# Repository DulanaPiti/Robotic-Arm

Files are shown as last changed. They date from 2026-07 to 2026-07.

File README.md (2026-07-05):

# 6-DOF Industrial Robotic Arm

## Overview
This repository contains the hardware design, simulation files, and documentation for a 6-DOF (Degrees of Freedom) industrial robotic arm. This system was developed by team **Neural Nexus** for the EN2160 Electronic Design Realization module. 

The project encompasses custom high-speed PCB designs, mechanical part models, and a complete simulation environment for testing kinematics and control logic.

## Repository Structure

* **`/Encoder PCB files`**
  * Contains the Altium Designer schematics, PCB layouts, and manufacturing files (Gerbers/NC Drill) for the joint encoder boards.
* **`/Main PCB files`**
  * Contains the Altium Designer project for the main control board, including power distribution and signal routing.
* **`/Part files`**
  * Mechanical CAD models (e.g., STEP/STL files) for the robotic arm links, base, and actuator mounts.
* **`/Robotic ARM Simulation`**
  * Simulation environment files to test and visualize the 6-DOF movements and control algorithms.

## Tools & Technologies Used
* **Hardware Design:** Altium Designer (Multi-layer PCB routing)
* **Simulation:** Made using Python
* **Mechanical CAD:** SolidWorks

## Getting Started
### Prerequisites
To view or modify the files in this repository, you will need:
* Altium Designer (for `.PcbDoc` and `.SchDoc` files)

## Team
**Neural Nexus**
* Dulana Nadith Pitiwaduge
* Lasan Perera
* Deneth Priyadarshana
* Isitha Dinujaya
* Mokshan Colombage

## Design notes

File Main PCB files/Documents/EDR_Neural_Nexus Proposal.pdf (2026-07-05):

# Project Proposal: Modular 6-DOF Industrial Robotic Arm

### NEURAL NEXUS

- One arm. Unlimited applications -

### 1. Executive Summary

This proposal outlines the strategic development and rapid market entry of an affordable, industrial-grade 6-Degrees of Freedom (DOF) robotic arm by NEURAL NEXUS. Industrial automation in Sri Lanka is currently stifled by the prohibitive cost of imported systems (1.0–1.5 million LKR). Our mission is to democratize high-end robotics by providing a performance-equivalent, modular system priced under 0.8 million LKR. This system is specifically tailored for the unique constraints of local SMEs, garment factories, and educational institutions, facilitating a rapid transition towards “Industry 4.0” through localized innovation and a compressed 3-month development cycle.

### 2. Market Justification & Target Segments

By 2026, the global shift toward “Physical AI” has transformed automation from a luxury into a competitive necessity. While developed nations have already reached a peak of efficiency through the implementation of “dark factories”—fully autonomous, unlit production lines emerging markets like Sri Lanka face a significant innovation-execution gap.
Despite a surplus of innovative ideas, the lack of local resources and high import costs typically delay the domestic adoption of such technologies by an estimated 6 to 8 years. Our development of a localized robotic arm serves as a strategic intervention to bridge this gap through three primary objectives:
- Lead-Time Reduction: By providing immediate, locally-available automation, we significantly reduce the lead time for industries that are currently underserved by global manufacturers focused on highvolume automotive lines.
- Market Alignment: We are entering a market where the industry explicitly expects local automation solutions. By offering a high-precision, low-cost alternative, we make advanced robotics accessible to a broader range of local enterprises.
- Ecosystem Development: Beyond the hardware, this project acts as a catalyst for a domestic supply chain. Our approach encourages the production of custom motors and specialized industrial materials within Sri Lanka, fostering a self-sustaining ecosystem for local high-tech manufacturing.

Primary Target Segments
- SME Manufacturing: Packaging, food processing, bottling, and repetitive material handling.
- Garment Industry: Automating fabric sorting, folding, and repetitive assembly tasks.
- Electronics Assembly: High-speed PCB placement, soldering, and quality inspection.
- Educational Institutes: Providing universities with a robust R&D platform for AI training.STEM Education
- Custom Automation: Local startups requiring non-standard tool integrations for niche processes.

### 3. Technical Specifications

To ensure industrial-grade reliability, our system adheres to the following engineering benchmarks:

Component/Feature | Specification / Requirement
Degrees of Freedom (DOF) | 6 (Waist, Shoulder, Elbow, and 3-Axis Spherical Wrist)
Rated Payload / Reach | 3.0 kg (Rated) / 750 mm (Spherical workspace)
Repeatability Spec | ±0.5 mm (High-resolution absolute encoders)
Structural Integrity | CNC-machined Aerospace-grade Aluminum and Steel
Control Architecture | Closed-loop real-time control; Inverse Kinematics (IK) processing
Drive System | High-torque stepper motors with customized plantery gearboxes
Safety Systems | Emergency Stop, Overcurrent Protection, Physical limit Sensors

Table 1: Core Technical Benchmarks for Industrial Deployment

### 4. Modular Ecosystem: Swappable Tool-Heads

The versatility of the NEURAL NEXUS arm lies in its rapid-change modular interface:
– Gripper Head: Mechanical picking and sorting for small parts.
– Vacuum Suction Head: Ideal for box handling, palletizing, and delicate flat sheets. – Screwdriver Head: Precision torque-controlled assembly for electronics.
– Vision Module: Integrated AI-enabled camera for real-time object recognition.

### 5. Market Approach & Sales Strategy

NEURAL NEXUS differentiates itself through a disruptive price-to-performance ratio and a localized support ecosystem designed to minimize industrial downtime.

Competitive Pricing Model
Our pricing is structured to lower the barrier to entry while maintaining sustainable margins.

– Target Selling Price (Base Unit): 350,000 – 500,000 LKR.

– Price Advantage: ∼50% lower than entry-level imported units from major global brands.

– Add-on Modules: Specialized heads priced at 35,000 – 85,000 LKR.

– Software Tiers: Core control is included; AI-vision upgrades are sold as yearly licenses.

Sales Channels & Market Penetration
To capture the Sri Lankan market effectively, we utilize a multi-pronged approach:

– The ”Trojan Horse” Strategy: Enter a factory by automating one specific bottleneck (e.g., bottling) to demonstrate ROI within 6 months, justifying further installations.

– Automation-as-a-Service (AaaS): Offer a lease model where clients pay per 1,000 cycles.

– B2B Partnerships: Partnering with local consultants who design production lines.

– Education Bundles: Providing technical colleges with a ”Robotics Lab Starter Kit.”

The Local Support Advantage
The primary deterrent for local firms is the lack of on-site support for international systems.

– 24/48-Hour Service Guarantee: On-site support and local inventory of spare parts.

– Customization Service: Bespoke tool-head design for localized industry needs (e.g., textile handling).

### 6. Project Budget (Estimated for MVP Prototype)

Item Category | Description | Cost (LKR)
Actuators & Feedback | 6x Industrial Grade High-torque steppers with Encoders | 150,000
Controller & Logic | Industrial-grade Central Controller and I/O interface | 45,000
Structural Components | CNC-machined metal frame, precision bearings, and housing | 50,000
Initial Tooling | Prototypes for Gripper and Vacuum Suction modules | 35,000
Sensors & Safety | Limit switches, Emergency stop, Power management circuits | 40,000
R&D & Iteration | Software development and rapid prototyping contingency | 60,000
TOTAL COST | | 380,000 LKR

Table 2: Prototype Development Budget (MVP Phase)

### 7. Accelerated Implementation Timeline (3 Months)

The project utilizes a parallel-track development strategy to meet a 12-week deployment goal.

– Month 1: Kinematic modeling, structural design validation, and component sourcing.
– Month 2: CNC fabrication of frames, actuator mounting, and control logic integration.
– Month 3: Stress testing, UI/UX refinement for friendly visible control, and pilot deployment.

### 8. Future Improvements

NEURAL NEXUS aims to integrate Agentic AI for autonomous task re-planning.A core improvement of this project is the development of a highly intuitive Graphical User Interface (GUI) designed to bridge the technical gap between complex robotics and the end-user. Traditionally, reconfiguring a robotic arm for a new task requires specialized knowledge of programming languages or proprietary industrial controllers. Our solution removes this barrier

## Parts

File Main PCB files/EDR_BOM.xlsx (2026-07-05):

Line # | Name | Description | Designator | Revision ID | Revision State | Revision Status | Quantity | TargetPrice | Manufacturer 1 | Manufacturer Part Number 1 | Manufacturer Lifecycle 1 | Supplier 1 | Supplier Part Number 1 | Supplier Unit Price 1 | Supplier Subtotal 1
 | 0R | Resistor, AS 0603 0R Jumper 100mW, AEC-Q, Anti-Sulur | Bourns CR0603AJ/-000EAS | R26, SB1, SB2 |  | Not managed |  | 3 | 0 | Bourns | CR0603AJ/-000EAS | Volume Production | Mouser | 652-CR0603AJ/-000EAS | 0.02 | 0.2
 | 0.1uF 0805 | 0.1 ÂµF Â±10% 50V Ceramic Capacitor X7R 0805 (2012 Metric) | C27, C30 |  | Not managed |  | 2 | 0 | Samsung Electro-Mechanics | CL21B104KBCNNNC | Volume Production | DigiKey | 1276-1003-1-ND | 0.1 | 0.2
 | 1k | 1 kOhms Â±1% 0.063W, 1/16W Chip Resistor 0402 (1005 Metric) Moisture Resistant Thick Film | R49 |  | Not managed |  | 1 | 0 | Yageo Group | RC0402FR-071KL | Volume Production | Mouser | 603-RC0402FR-071KL | 0.1 | 0.1
 | 1N4148W | Small Signal Diode, SOD-123F, 100V, 0.15A, 150Â°C | D1, D2 |  | Not managed |  | 2 | 0 | Diodes Inc. | 1N4148W-7-F | Volume Production | Avnet | 52R3924 | 0.117 | 0.234
 | 1N5819HW-7-F | Diode Schottky 40 V 1A Surface Mount SOD-123 | D12, D13 |  | Not managed |  | 2 | 0 | Diodes Inc. | 1N5819HW-7-F | Volume Production | Newark | 1N5819HW-7-F | 0.284 | 0.568
 | 1uF | 1 ÂµF Â±10% 6.3V Ceramic Capacitor X5R 0402 (1005 Metric) | C34 |  | Not managed |  | 1 | 0 | TAIYO YUDEN | JMK105BJ105KV-F | Not Recommended for New Design | Arrow Electronics | JMK105BJ105KV-F | 0.0015 | 0.0015
 | 1uF 0603 | 1 ÂµF -20%, +80% 16V Ceramic Capacitor Y5V (F) 0603 (1608 Metric) | C15, C17 |  | Not managed |  | 2 | 0 | Yageo Group | CC0603ZRY5V7BB105 | Volume Production | DigiKey | 311-1372-1-ND | 0.1 | 0.2
 | 1uF 0603 | 1 ÂµF -20%, +80% 16V Ceramic Capacitor Y5V (F) 0603 (1608 Metric) | C39 |  | Not managed |  | 1 | 0 | Yageo Group | CC0603ZRY5V7BB105 | Volume Production | DigiKey | 311-1372-1-ND | 0.1 | 0.1
 | 1.5 kOhm | 1.5 kOhms Â±1% 0.063W, 1/16W Chip Resistor 0402 (1005 Metric) Moisture Resistant Thick Film | R4 |  | Not managed |  | 1 | 0 | Yageo Group | RC0402FR-071K5L | Volume Production | Farnell | RC0402FR-071K5L | 0.00551 | 0.05507
 | 1.5 kOhm | 1.5 kOhms Â±1% 0.063W, 1/16W Chip Resistor 0402 (1005 Metric) Moisture Resistant Thick Film | R25, R34 |  | Not managed |  | 2 | 0 | Yageo Group | RC0402FR-071K5L | Volume Production | Farnell | RC0402FR-071K5L | 0.00551 | 0.05507
 | 2N7002LT3G | RoHS Compliant; Small package discrete | Q1, Q2 |  | Not managed |  | 2 | 0 | onsemi | 2N7002LT3G | Volume Production | Avnet | 09R9864 | 0.065 | 0.13
 | 2.2uF 0603 | 2.2 ÂµF Â±10% 25V Ceramic Capacitor X5R 0603 (1608 Metric) | C12, C13 |  | Not managed |  | 2 | 0 | Yageo Group | CC0603KRX5R8BB225 | Volume Production | Mouser | 603-CC603KRX5R8BB225 | 0.13 | 0.26
 | 3.3uH | FHD4020S-3R3MT | L2 |  | Not managed |  | 1 | 0 | Cjiang | FHD4020S-3R3MT | Unknown
 | 4.7uF 0603 | No Description Available | C23 |  | Not managed |  | 1 | 0 | Yageo Group | CC0603MRX5R8BB475 | Volume Production
 | 4.7uF X7R | C Series 0805 4.7 uF 10 V Â±10% Tolerance X7R SMT Multilayer Ceramic Capacitor | C24, C25 |  | Not managed |  | 2 | 0 | TDK | C2012X7R1A475K125AC | Volume Production | Arrow Electronics | C2012X7R1A475K125AC | 0.1822 | 0.3644
 | 4.7uF X7R | C Series 0805 4.7 uF 10 V Â±10% Tolerance X7R SMT Multilayer Ceramic Capacitor | C38 |  | Not managed |  | 1 | 0 | TDK | C2012X7R1A475K125AC | Volume Production | Arrow Electronics | C2012X7R1A475K125AC | 0.1822 | 0.1822
 | 5.1k | 5.1 kOhms Â±1% 0.063W, 1/16W Chip Resistor 0402 (1005 Metric) Automotive AEC-Q200 Thick Film | R47, R48, R52, R53 |  | Not managed |  | 4 | 0 | Stackpole Electronics | RMCF0402FT5K10 | Volume Production | Mouser | 708-RMCF0402FT5K10 | 0.012 | 0.12
 | 10k 0402 | 301010004 | J17, J19, R7, R8, R24 |  | Not managed |  | 5 | 0 | Yageo Group | RC0402JR-0710KL | Volume Production | Farnell | RC0402JR-0710KL | 0.006 | 0.05998
 | 10pF | 10 pF Â±5% 25V Ceramic Capacitor C0G, NP0 0402 (1005 Metric) | C4, C5 |  | Not managed |  | 2 | 0 | Yageo Group | CC0402JRNPO8BN100 | Volume Production | Newark | CC0402JRNPO8BN100 | 0.012 | 0.12
 | 10uF 0805 | SMD capacitor X7R(MURATA) with capacitance 10uF Tol.10%. Rated voltage 25Vdc 125C | C28, C29 |  | Not managed |  | 2 | 0 | Murata | GRM21BZ71E106KE15L | Volume Production | Conrad | 3425898 | 0.16272 | 0.32543
 | 12pF | 0402 12 pF 50 V Â±1% Tolerance C0G SMT Multilayer Ceramic Capacitor | C8, C9 |  | Not managed |  | 2 | 0 | Murata | GRM1555C1H120FA01D | Not Recommended for New Design | DigiKey | 490-6196-1-ND | 0.1 | 0.2
 | 20k | 20 kOhms Â±1% 0.1W, 1/10W Chip Resistor 0603 (1608 Metric) Moisture Resistant Thick Film | R31 |  | Not managed |  | 1 | 0 | Yageo Group | RC0603FR-0720KL | Volume Production | Farnell | RC0603FR-0720KL | 0.01 | 0.09996
 | 22R 0402 | 22 Ohms Â±1% 0.063W, 1/16W Chip Resistor 0402 (1005 Metric) Moisture Resistant Thick Film | R9, R10, R11, R12, R13, R14, R15, R16, R17, R18, R19, R20, R54, R55, R56, R57, R58 |  | Not managed |  | 17 | 0 | Yageo Group | RC0402FR-0722RL | Volume Production | Newark | RC0402FR-0722RL | 0.004 | 0.068
 | 22R 0402 | 22 Ohms Â±1% 0.063W, 1/16W Chip Resistor 0402 (1005 Metric) Moisture Resistant Thick Film | R38, R39, R40, R41, R42, R43 |  | Not managed |  | 6 | 0 | Yageo Group | RC0402FR-0722RL | Volume Production | Newark | RC0402FR-0722RL | 0.004 | 0.04
 | 22uF 1210 | SMD capacitor X7R(EIA) with capacitance 22uF Tol.10%. Rated voltage 25Vdc 125C | C31, C32 |  | Not managed |  | 2 | 0 | Murata | GRM32ER71E226KE15L | Volume Production | Conrad | 3424926 | 0.62762 | 1.26
 | 22.1k | 22.1 kOhms Â±1% 0.1W, 1/10W Chip Resistor 0603 (1608 Metric) Automotive AEC-Q200 Thick Film | R50 |  | Not managed |  | 1 | 0 | Stackpole Electronics | RMCF0603FT22K1 | Volume Production | DigiKey | RMCF0603FT22K1CT-ND | 0.1 | 0.1
 | 25MHZ | 25 MHz Â±30ppm Crystal 10pF 60 Ohms 4-SMD, No Lead | X2 |  | Not managed |  | 1 | 0 | Abracon | ABM8G-25.000MHZ-B4Y-T | Volume Production | Farnell | ABM8G-25.000MHZ-B4Y-T | 0.65974 | 0.65974
 | 32.768KHZ | Description | X1 |  | Not managed |  | 1 | 0 | Abracon | ABS07-32.768KHZ-7-T | Volume Production | Newark | ABS07-32.768KHZ-7-T | 0.578 | 0.578
 | 36.1k | RES SMD 36.1KOHM 0.1% 1/10W 0603 | R32 |  | Not managed |  | 1 | 0 | Yageo Group | RT0603BRD0736K1L | Volume Production | Mouser | 603-RT0603BRD0736K1L | 0.1 | 0.1
 | 47 kOhm | 47 kOhms Â±1% 0.1W, 1/10W Chip Resistor 0603 (1608 Metric) Moisture Resistant Thick Film | R35, R36, R37, R44, R45 |  | Not managed |  | 5 | 0 | Yageo Group | RC0603FR-0747KL | Volume Production | Mouser | 603-RC0603FR-0747KL | 0.013 | 0.13
 | 47.5k | 47.5 kOhms Â±1% 0.063W, 1/16W Chip Resistor 0402 (1005 Metric) Moisture Resistant Thick Film | R51 |  | Not managed |  | 1 | 0 | Yageo Group | RC0402FR-0747K5L | Volume Production | Arrow Electronics | RC0402FR-0747K5L | 0.0005 | 0.0005
 | 49.9 R | Resistor,Thick Film,49.9 Ohms,0.063 W,1%,SMT,0402,TCR 37 ppm/DegC,Cut Tape | Vishay Dale CRCW040249R9FKED | R29 |  | Not managed |  | 1 | 0 | Vishay | CRCW040249R9FKED | Volume Production | DigiKey | 541-49.9LCT-ND | 0.1 | 0.1
 | 73.2k | RES 73.2K OHM 1% 1/16W 0402 | R33 |  | Not managed |  | 1 | 0 | Stackpole Electronics | RMCF0402FT73K2 | Volume Production | Arrow Electronics | RMCF0402FT73K2 | 0.016 | 0.016
 | 100 nF 0402 | 0.1 ÂµF Â±10% 10V Ceramic Capacitor X7R 0402 (1005 Metric) | C1, C2, C7, C11, C14, C16, C18, C19, C20, C21, C22, C26, C36, C37 |  | Not managed |  | 14 | 0 | Samsung Electro-Mechanics | CL05B104KP5NNNC | Volume Production | Mouser | 187-CL05B104KP5NNNC | 0.016 | 0.224
 | 100 nF 0402 | 0.1 ÂµF Â±10% 10V Ceramic Capacitor X7R 0402 (1005 Metric) | C35 |  | Not managed |  | 1 | 0 | Samsung Electro-Mechanics | CL05B104KP5NNNC | Manual Solution
 | 100kOhm | 100 kOhms Â±1% 0.063W, 1/16W Chip Resistor 0402 (1005 Metric) Moisture Resistant Thick Film | R5 |  | Not managed |  | 1 | 0 | Yageo Group | RC0402FR-07100KL | Volume Production | Mouser | 603-RC0402FR-07100KL | 0.1 | 0.1
 | 100kOhm | 100 kOhms Â±1% 0.063W, 1/16W Chip Resistor 0402 (1005 Metric) Moisture Resistant Thick Film | R30 |  | Not managed |  | 1 | 0 | Yageo Group | RC0402FR-07100KL | Volume Production | Mouser | 603-RC0402FR-07100KL | 0.1 | 0.1
 | 100kOhm | 100 kOhms Â±1% 0.1W, 1/10W Chip Resistor 0603 (1608 Metric) Moisture Resistant Thick Film | R46 |  | Not managed |  | 1 | 0 | Yageo Group | RC0603FR-07100KL | Volume Production | DigiKey | 311-100KHRCT-ND | 0.1 | 0.1
 | 100Mhz | Description | L1 |  | Not managed |  | 1 | 0 | Murata | BLM15PD121SN1D | Volume Production | DigiKey | 490-5203-1-ND | 0.1 | 0.1
 | 100pF | 100 pF Â±5% 50V Ceramic Capacitor C0G, NP0 0402 (1005 Metric) | C33 |  | Not managed |  | 1 | 0 | Samsung Electro-Mechanics | CL05C101JB5NNNC | Volume Production | Farnell | CL05C101JB5NNNC | 0.00786 | 0.07864
 | 100R | 100 Ohms Â±1% 0.063W, 1/16W Chip Resistor 0402 (1005 Metric) Moisture Resistant Thick Film | R2, R3 |  | Not managed |  | 2 | 0 | Yageo Group | RC0402FR-07100RL | Volume Production | Mouser | 603-RC0402FR-07100RL | 0.008 | 0.08
 | 169k | 169 kOhms Â±1% 0.1W, 1/10W Chip Resistor 0603 (1608 Metric) Automotive AEC-Q200 Thick Film | R28 |  | Not managed |  | 1 | 0 | Stackpole Electronics | RMCF0603FT169K | Volume Production | Arrow Electronics | RMCF0603FT169K | 0.002 | 0.004
 | 330R | 330 Ohms Â±1% 0.063W, 1/16W Chip Resistor 0402 (1005 Metric) Moisture Resistant Thick Film | R1 |  | Not managed |  | 1 | 0 | Vishay | CRCW2512330RFKEG | Volume Production | Newark | CRCW2512330RFKEG | 0.015 | 0.015
 | 330R | 330 Ohms Â±1% 0.063W, 1/16W Chip Resistor 0402 (1005 Metric) Moisture Resistant Thick Film | R6, R21, R22, R23, R27 |  | Not managed |  | 5 | 0 | Yageo Group | RC0402FR-07330RL | Volume Production | Newark | RC0402FR-07330RL | 0.004 | 0.04
 | B2B-XH-A(LF)(SN) | B2B-XH-A(LF)(SN) CONN HEADER VERT 2POS 2.5MM | LED1 |  | Not managed |  | 1 | 0 | JST | B2B-XH-A (LF) (SN) | Volume Production | Newark | B2B-XH-A (LF)(SN) | 0.092 | 0.092
 | B3B-XH-A | Connector Header Through Hole 3 position 0.098 (2.50mm) | J11, J12, J13 |  | Not managed |  | 3 | 0 | JST | B3B-XH-A(LF)(SN) | Volume Production | Arrow Electronics | B3B-XH-A(LF)(SN) | 0.1055 | 0.3165
 | B6B-XH-A | Connector Header Through Hole 6 position 0.098 (2.50mm) | J5, J6, J7 |  | Not managed |  | 3 | 0 | JST | B6B-XH-A | Volume Production
 | BLUE LED | LED RED CLEAR SMD | D3 |  | Not managed |  | 1 | 0
 | Buzzer |  | LS1 |  | Not managed |  | 1 | 0 | KINGSTATE | KPEG242 | Manual Solution
 | CP2102N-A02-GQFN24R | IC USB TO UART BRIDGE QFN24 | U11 |  | Not managed |  | 1 | 0 | Silicon Lab | CP2102N-A02-GQFN24R | Volume Production | Mouser | 634-CP2102NA02QFN24R | 4.14 | 4.14
 | ECA-1HM471 | Aluminum Electrolytic Capacitor, 470 uF, +/- 20%, 50 V, -40 to 85 degC, 2-Pin THD, RoHS, Bulk | C3, C6, C10 | CMP-001-00032-8 | Draft | Up to date | 3 | 0 | Panasonic | ECA-1HM471 | Volume Production | Mouser | 667-ECA-1HM471 | 0.91 | 2.73
 | ESD | Transient Voltage Suppressors for ESD Protection | D9 |  | Not managed |  | 1 | 0 | LEIDITECH | LESD5D5.0CT1G | Unknown
 | LED | LED RED CLEAR SMD | D8, D10, D11 |  | Not managed |  | 3 | 0
 | M4 | Connector Header Through Hole 5 position 0.098 (2.50mm) | J2 |  | Not managed |  | 1 | 0 | JST | B5B-XH-A | Volume Production | DigiKey | 455-B5B-XH-A-ND | 0.2 | 0.2
 | M5 | Connector Header Through Hole 5 position 0.098 (2.50mm) | J4 |  | Not managed |  | 1 | 0 | JST | B5B-XH-A | Volume Production | DigiKey | 455-B5B-XH-A-ND | 0.2 | 0.2
 | M6 | Connector Header Through Hole 5 position 0.098 (2.50mm) | J3 |  | Not managed |  | 1 | 0 | JST | B5B-XH-A | Volume Production | DigiKey | 455-B5B-XH-A-ND | 0.2 | 0.2
 | MAX809TEUR+T | 3-Pin Microprocessor Reset Circuits | U1 |  | Not managed |  | 1 | 0 | Analog Devices | MAX809TEUR+T | Volume Production | Mouser | 700-MAX809TEURT | 5.31 | 5.31
 | MMUN2211LT1G | TRANS PREBIAS NPN 50V SOT23-3 | U5 |  | Not managed |  | 1 | 0 | onsemi | MMUN2211LT1G | Volume Production | Newark | MMUN2211LT1G | 0.011 | 0.011
 | PCB fuse mount | 5mm Low Profile Holder | F1, F2 |  | Not managed |  | 2 | 0
 | RJ45 M1 | CONN MOD JACK 8P8C R/A SHIELDED | J8 |  | Not managed |  | 1 | 0 | Amphenol Communications Solutions | RJHSE5380 | Volume Production | Avnet | RJHSE5380 | 0.86193 | 0.86193
 | RJ45 M2 | CONN MOD JACK 8P8C R/A SHIELDED | J9 |  | Not managed |  | 1 | 0 | Amphenol Communications Solutions | RJHSE5380 | Volume Production | Avnet | RJHSE5380 | 0.86193 | 0.86193
 | RJ45 M3 | CONN MOD JACK 8P8C R/A SHIELDED | J10 |  | Not managed |  | 1 | 0 | Amphenol Communications Solutions | RJHSE5380 | Volume Production | Avnet | RJHSE5380 | 0.86193 | 0.86193
 | RJ45 M4 | CONN MOD JACK 8P8C R/A SHIELDED | J14 |  | Not managed |  | 1 | 0 | Amphenol Communications Solutions | RJHSE5380 | Volume Production | Avnet | RJHSE5380 | 0.86193 | 0.86193
 | RJ45 M5 | CONN MOD JACK 8P8C R/A SHIELDED | J15 |  | Not managed |  | 1 | 0 | Amphenol Communications Solutions | RJHSE5380 | Volume Production | Avnet | RJHSE5380 | 0.86193 | 0.86193
 | RJ45 M6 | CONN MOD JACK 8P8C R/A SHIELDED | J16 |  | Not managed |  | 1 | 0 | Amphenol Communications Solutions | RJHSE5380 | Volume Production | Avnet | RJHSE5380 | 0.86193 | 0.86193
 | SD03 | Description | U8 |  | Not managed |  | 1 | 0 | onsemi | ESD7351HT1G | Volume Production | Newark | ESD7351HT1G | 0.02 | 0.02
 | SP0402B-ULC-01ETG | Description | CR1, CR2, CR3, CR4, CR5, CR6, CR7, CR8, CR9, CR10, CR11, CR12, CR13, CR14, CR15, CR16 |  | Not managed |  | 16 | 0 | Littelfuse | SP0402B-ULC-01ETG | Volume Production | Farnell | SP0402B-ULC-01ETG | 0.21058 | 3.37
 | ST1L05CPU33R | Very low quiescent BiCMOS voltage regulator | U7 |  | Not managed |  | 1 | 0 | STMicroelectronics | ST1L05CPU33R | Volume Production | Arrow Electronics | ST1L05CPU33R | 0.5214 | 0.5214
 | STM32H743VIT6 | IC MCU 32BIT 2MB FLASH 100LQFP | U2 |  | Not managed |  | 1 | 0 | STMicroelectronics | STM32H743VIT6 | Volume Production | Arrow Electronics | STM32H743VIT6 | 14.28 | 14.28
 | SW | TOGGLE, 5A, 120VAC/28VDC SPDT, On-Off-On, Panel Mount, Through Hole | SW7, SW8 |  | Not managed |  | 2 | 0
 | SW Debug | Connector Header Through Hole 5 position 0.098 (2.50mm) | J1 |  | Not managed |  | 1 | 0 | Wurth Elektronik | 61300511121 | Volume Production | Mouser | 710-61300511121 | 0.26 | 0.26
 | TF-115-BCP9 | -25~+85 1.8mm Tin Deck MicroSD card (TF card) 260 C5191 Self bomb SMD SD Card Connectors ROHS | J20 |  | Not managed |  | 1 | 0 | XUNPU | TF-115-BCP9 | Manual Solution
 | TMC2209 |  | U3, U4, U6 |  | Not managed |  | 3 | 0
 | TPS56637RPAR | 4.5-V to 28-V, 6-A synchronous buck converter with ULQ-Mode 10-VQFN-HR -40 to 150 | U9 |  | Not managed |  | 1 | 0 | Texas Instruments | TPS56637RPAR | Volume Production
 | TS-1089S-02526 | Tactile Switch SPST 2.5mm 4.2mm x 3.25mm Surface Mount | SW1, SW2, SW3, SW4, SW5, SW6 |  | Not managed |  | 6 | 0 | Xunpu | TS-1089S-02526 | Unknown
 | USB C 16P | CONN RCP USB2.0 TYP C 16P SMD RA | J21 |  | Not managed |  | 1 | 0 | Global Connector Technology | USB4105-GF-A | Volume Production | Mouser | 640-USB4105-GF-A | 0.8 | 0.8
 | USB C 16P | CONN RCP USB2.0 TYP C 16P SMD RA | J22 |  | Not managed |  | 1 | 0 | Global Connector Technology | USB4105-GF-A | Volume Production | Mouser | 640-USB4105-GF-A | 0.8 | 0.8
 | W25Q64JVSSIQ | IC FLASH 64MBIT SPI/QUAD 8SOIC | U10 |  | Not managed |  | 1 | 0 | Winbond | W25Q64JVSSIQ | Volume Production | DigiKey | W25Q64JVSSIQ-ND | 1.11 | 1.11
 | WS2812C-2020 | Intelligent control LED integrated light source | D4, D5, D6, D7 |  | Not managed |  | 4 | 0 | Worldsemi | WS2812C-2020 | Unknown
 | XT60PW-M | Socket, DC supply, male, PIN: 2 | J18 |  | Not managed |  | 1 | 0 | Amass | XT60PW-M | Unknown

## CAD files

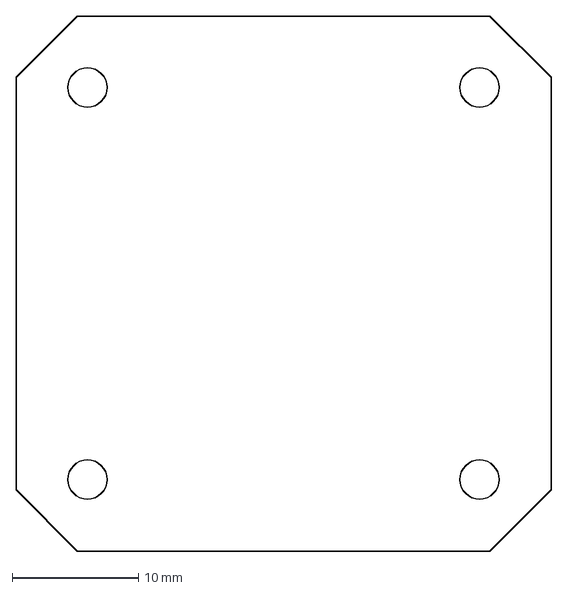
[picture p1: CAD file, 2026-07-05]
Main PCB files/nema_17_pcb.DXF
42.3 x 42.3 mm

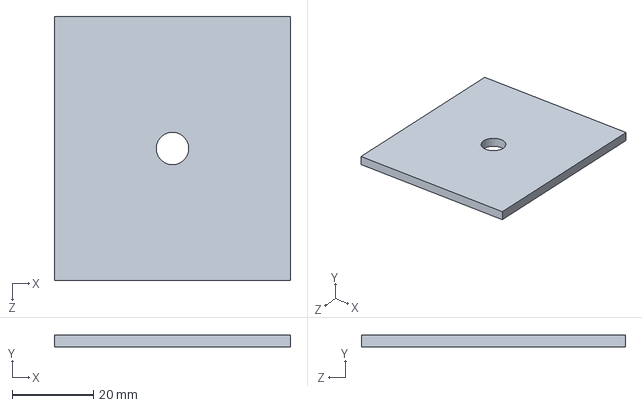
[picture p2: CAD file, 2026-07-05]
Part files/Corrected/Rotater_arm_part_rear_plate_2.SLDPRT
58.0 x 3.00 x 65.0 mm

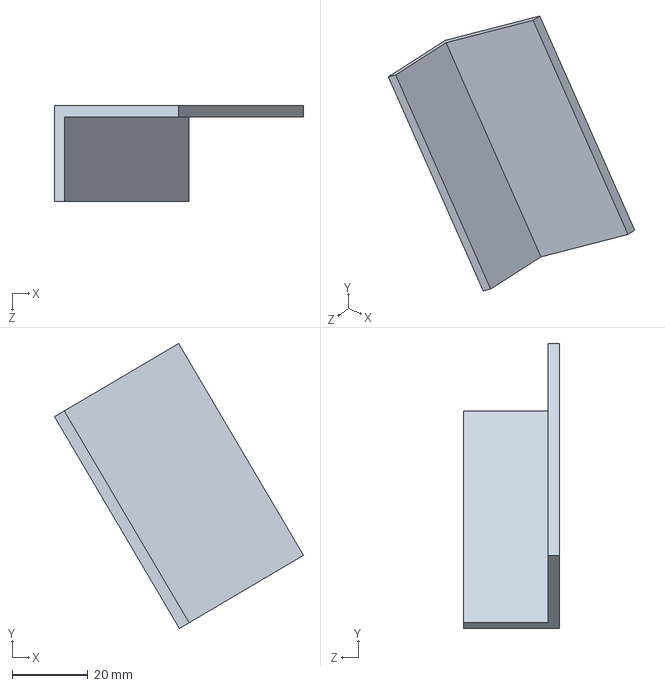
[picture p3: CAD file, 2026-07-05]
Part files/Dont need to edit/link_3_Motor_front_plate_inner_2.SLDPRT
65.8 x 75.3 x 25.4 mm

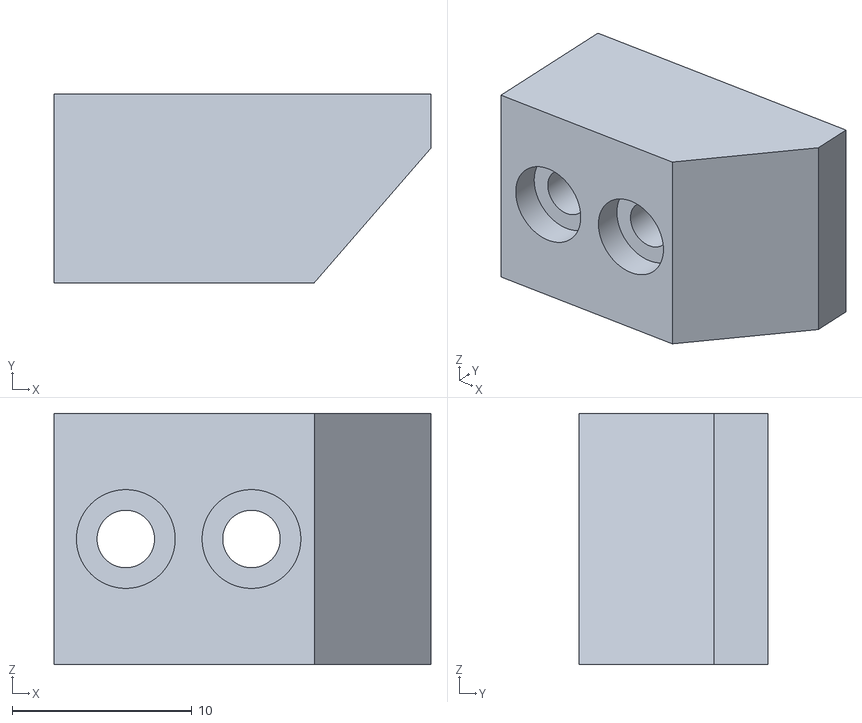
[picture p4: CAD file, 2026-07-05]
Robotic ARM Simulation/models/link6.STL
21.0 x 10.5 x 14.0

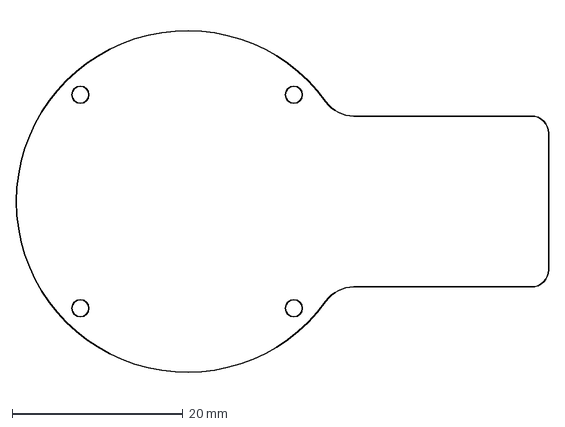
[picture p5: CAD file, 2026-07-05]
Main PCB files/nema_24_pcb.DXF
62.3 x 43.4 mm

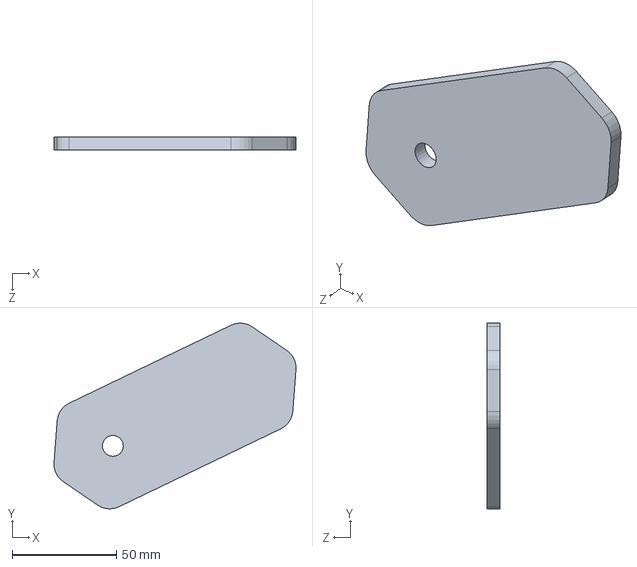
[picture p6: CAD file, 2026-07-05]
Part files/Corrected/Outer_arm_side_1.SLDPRT
115.8 x 88.9 x 6.00 mm

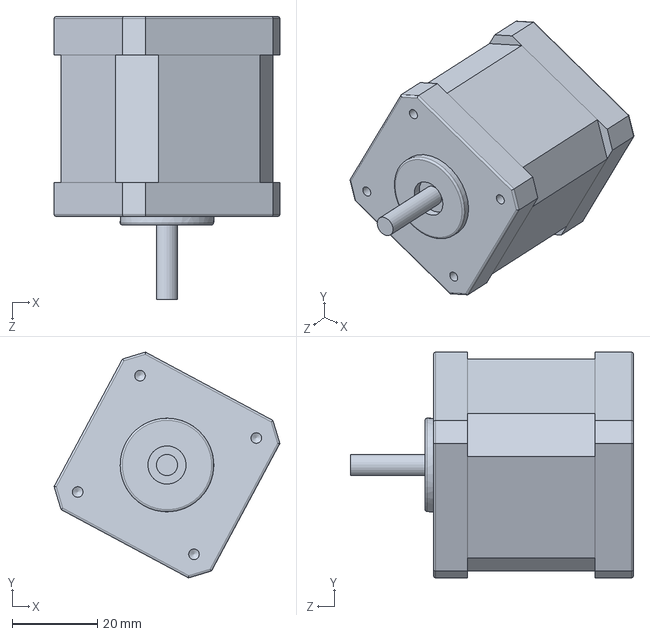
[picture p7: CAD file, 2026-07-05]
Part files/Dont need to edit/link_2_stepper.SLDPRT
53.1 x 53.1 x 66.5 mm

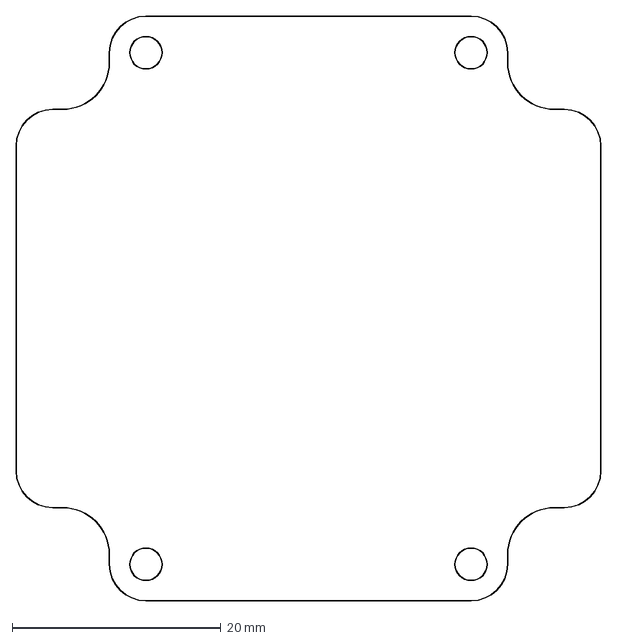
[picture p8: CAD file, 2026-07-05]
Main PCB files/nema_23_pcb.DXF
56.0 x 56.0 mm

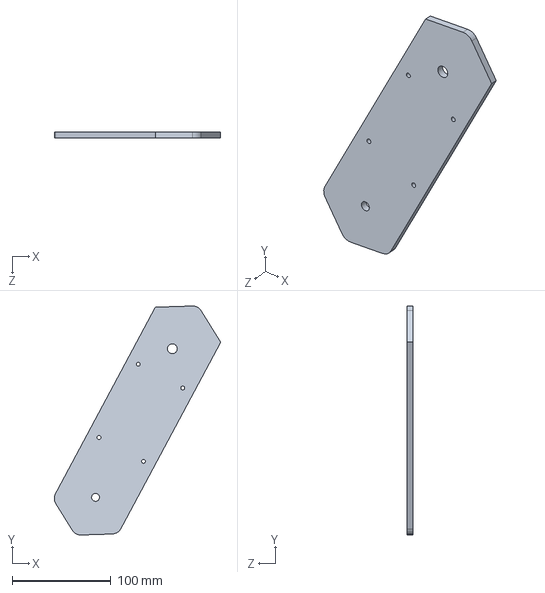
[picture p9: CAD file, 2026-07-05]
Part files/Corrected/link_1_part_2.SLDPRT
168.2 x 231.3 x 6.00 mm

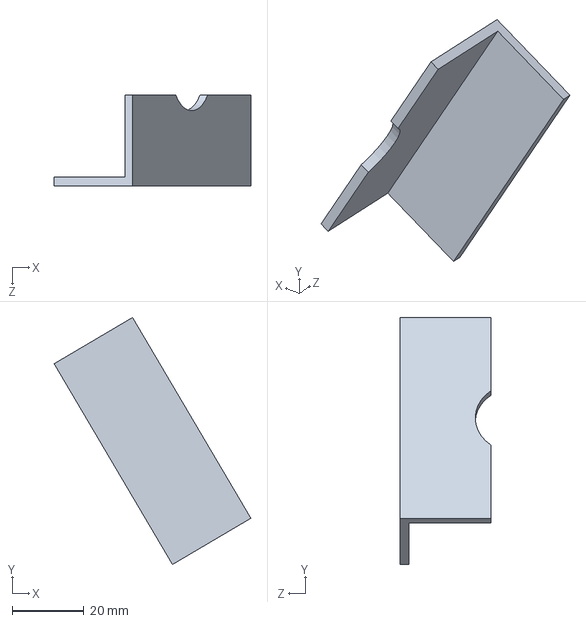
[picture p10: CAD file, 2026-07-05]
Part files/Dont need to edit/link_3_Motor_handling_plate_inner _1.SLDPRT
54.9 x 68.9 x 25.4 mm

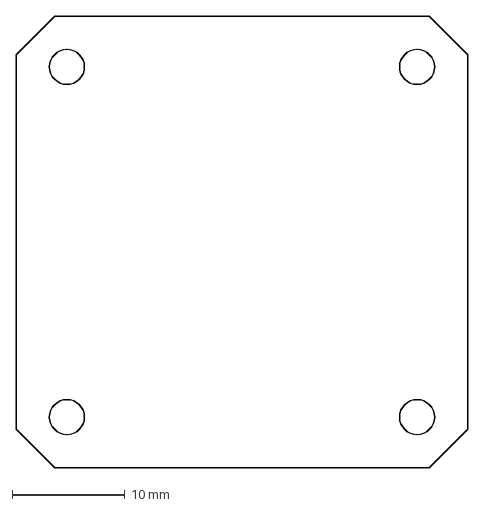
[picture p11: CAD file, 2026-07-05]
Main PCB files/nema_17_pancake_pcb.DXF
40.0 x 40.0 mm

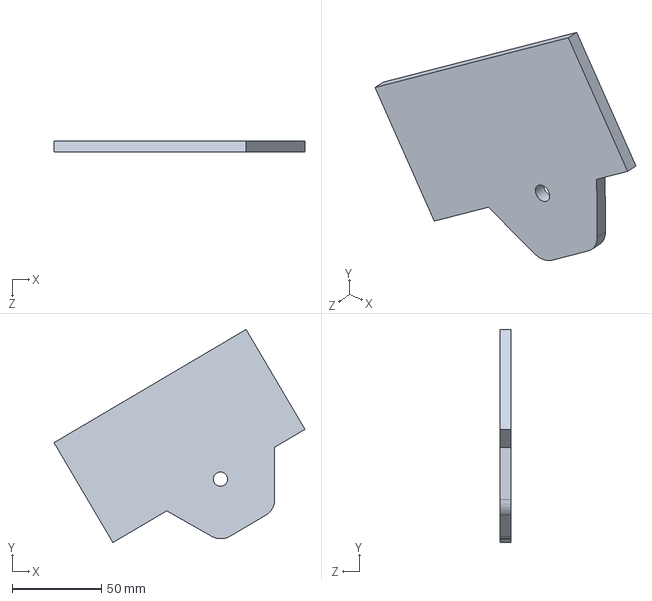
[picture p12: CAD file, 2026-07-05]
Part files/Corrected/link_3_part_1.SLDPRT
140.7 x 119.5 x 6.00 mm

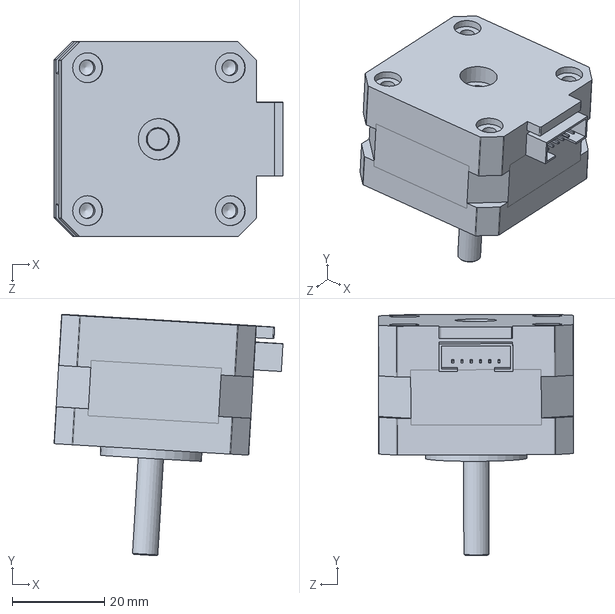
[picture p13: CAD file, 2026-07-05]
Part files/Dont need to edit/Outerst_stepper.SLDPRT
49.7 x 52.4 x 42.4 mm

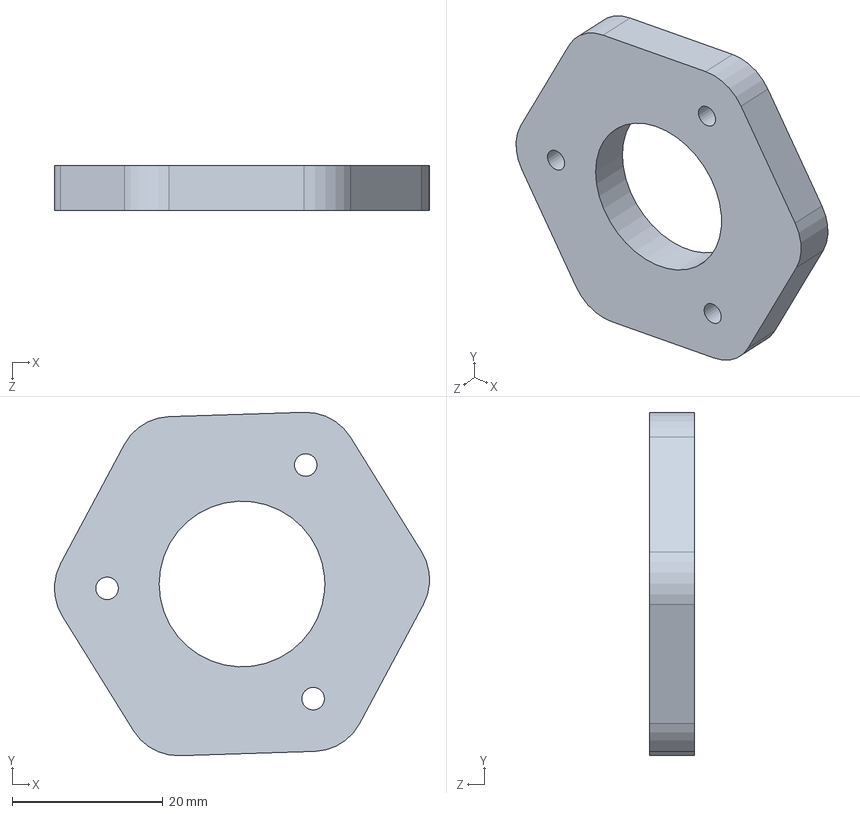
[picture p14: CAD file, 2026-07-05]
Part files/Corrected/link_2_part_1_plate.SLDPRT
49.8 x 45.6 x 6.00 mm

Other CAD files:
Part files/Assembly/Assem1.SLDASM
Part files/Dont need to edit/Motor_head_1.SLDPRT
Part files/Corrected/Base_L_2_next_small_pad.SLDPRT
Part files/Dont need to edit/rod_3.SLDPRT
Part files/Corrected/Base_L_1_next.SLDPRT
Part files/Corrected/Base_L_1_next_pad.SLDPRT
Part files/Corrected/Base_L_1_next_small_pad.SLDPRT
Part files/Corrected/Base_L_1_next_small_pad_inner.SLDPRT
Part files/Corrected/Base_L_2_next.SLDPRT
Part files/Corrected/Base_L_2_next_pad.SLDPRT
Part files/Corrected/Base_plate.SLDPRT
Part files/Corrected/Outer_outer_arm_side_1.SLDPRT
Part files/Corrected/Outer_outer_arm_side_2.SLDPRT
Part files/Corrected/Outer_outer_arm_side_plate_1.SLDPRT
Part files/Corrected/Outer_outer_arm_side_plate_2.SLDPRT
Part files/Corrected/Outest_front_plate.SLDPRT
Part files/Corrected/Rotater_arm_part_rear_plate_1.SLDPRT
Part files/Corrected/Rotater_arm_part_side_1.SLDPRT
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

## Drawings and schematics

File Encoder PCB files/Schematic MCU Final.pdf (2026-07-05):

# SYSTEM RST

# SWITCHES

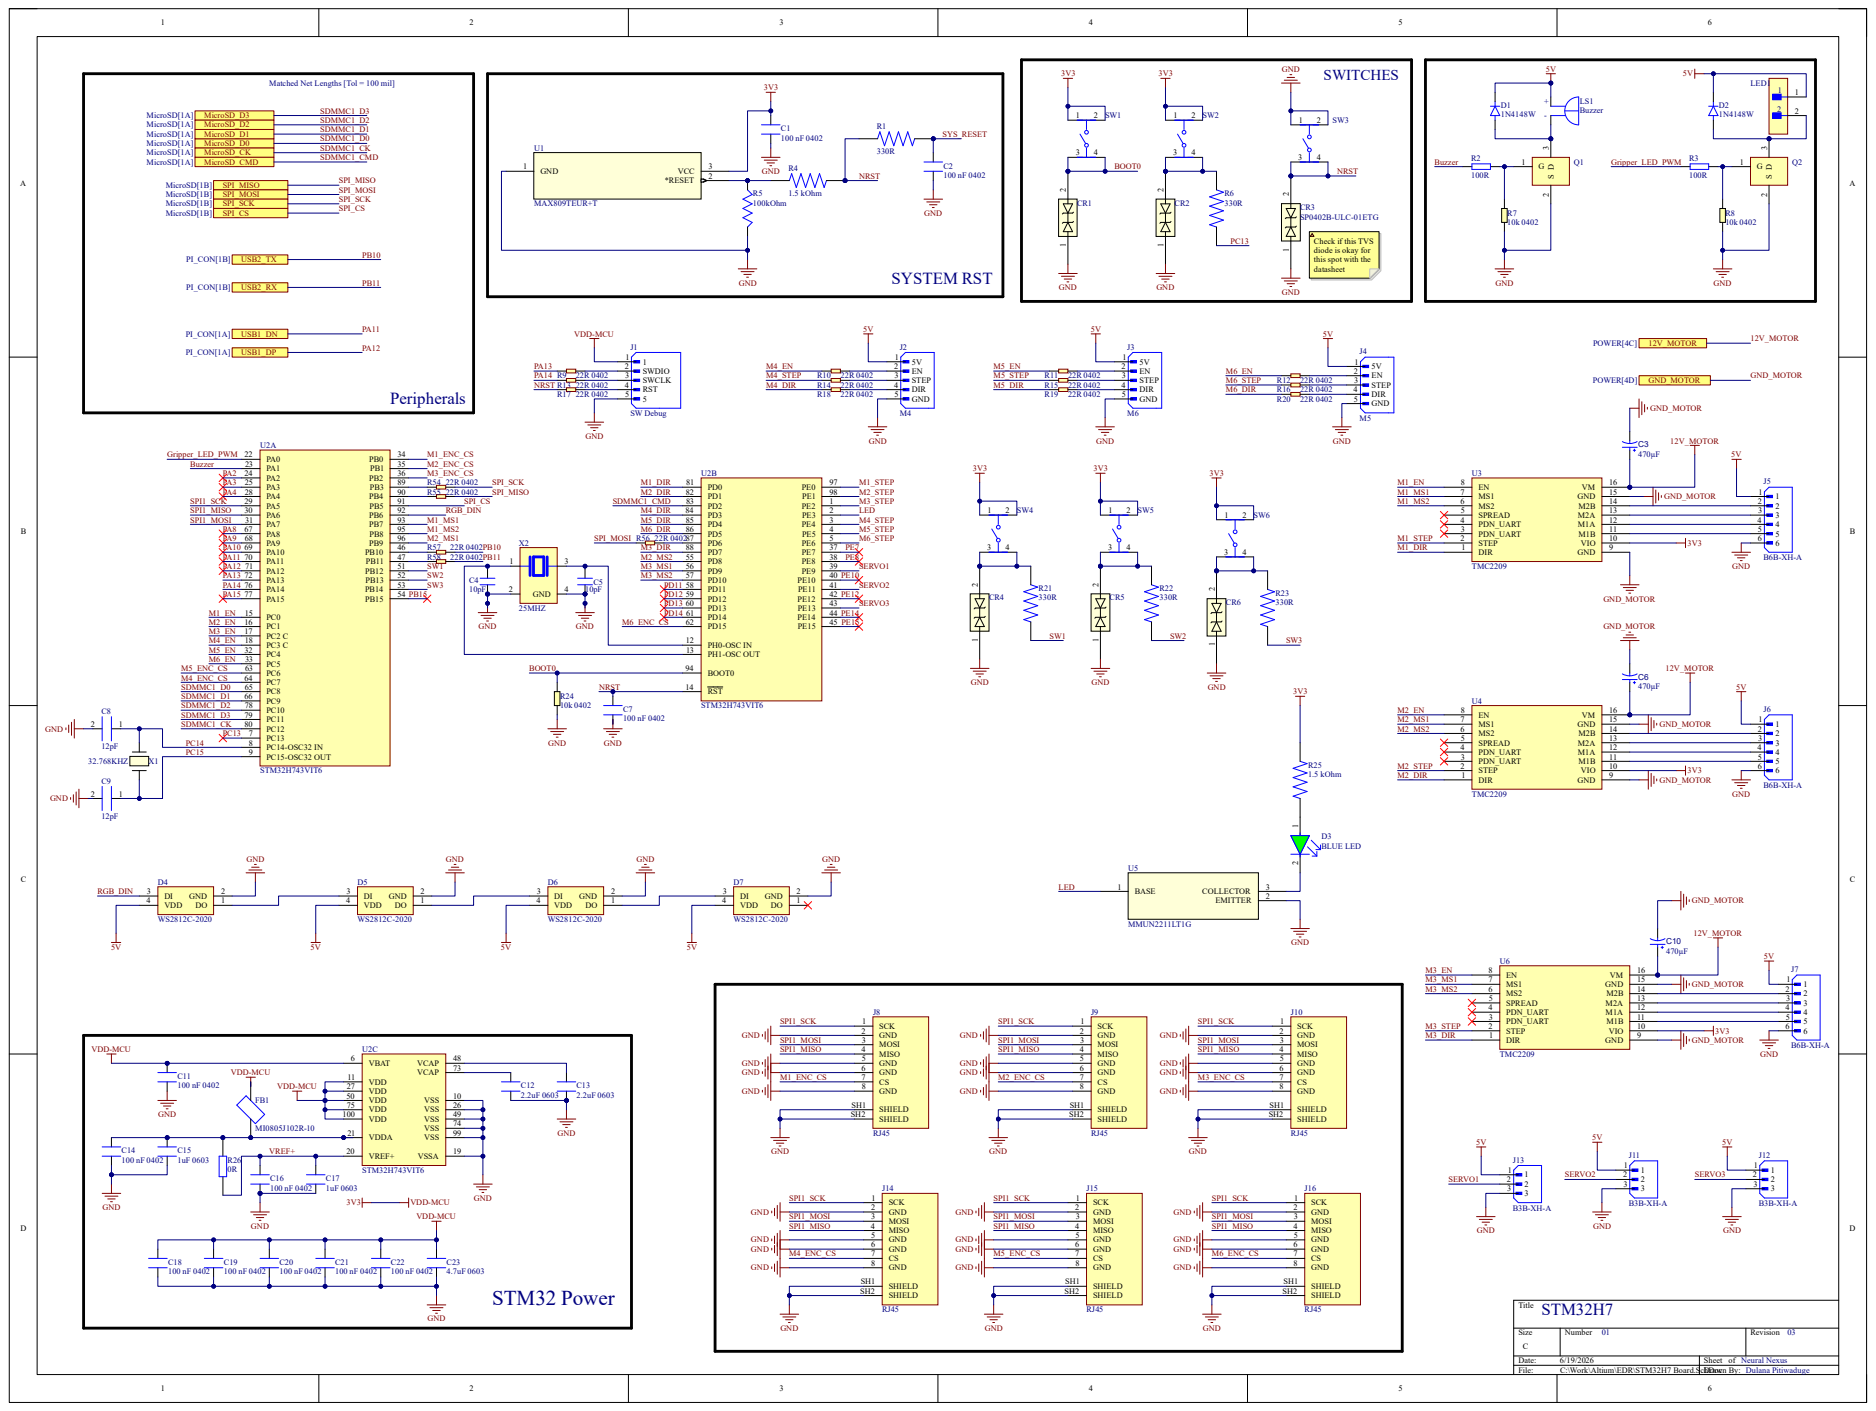
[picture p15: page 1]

Matched Net Lengths [Tol = 100 mil]

Check if this TVS
diode is okay for
this spot with the
datasheet

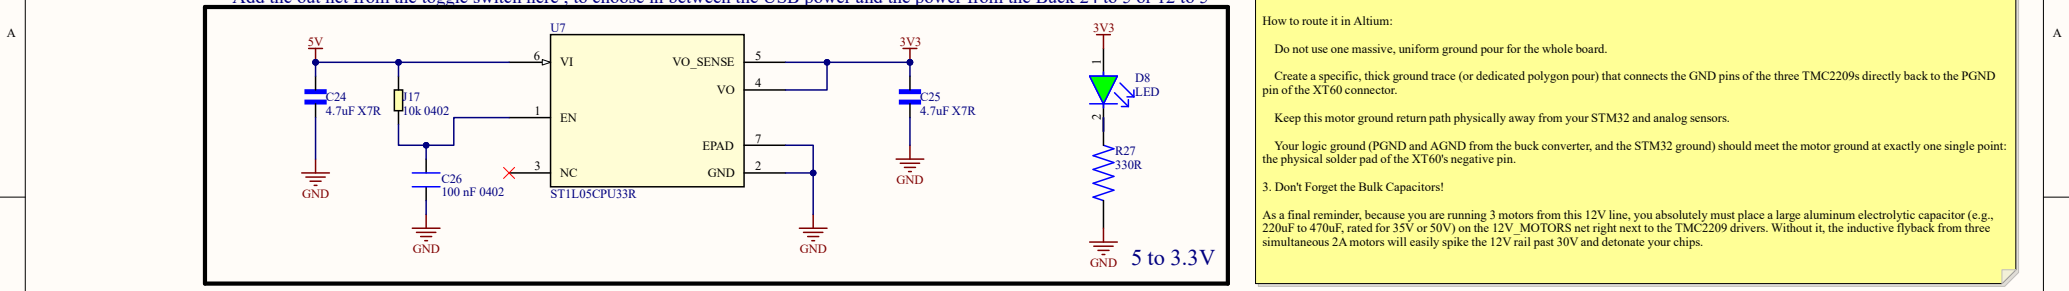
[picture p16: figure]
GND; VO_SENSE; EPAD; ST1L05CPU33R; D8 LED; How to route it in Altium:; pin of the XT60 connector.; 3. Don't Forget the Bulk Capacitors!
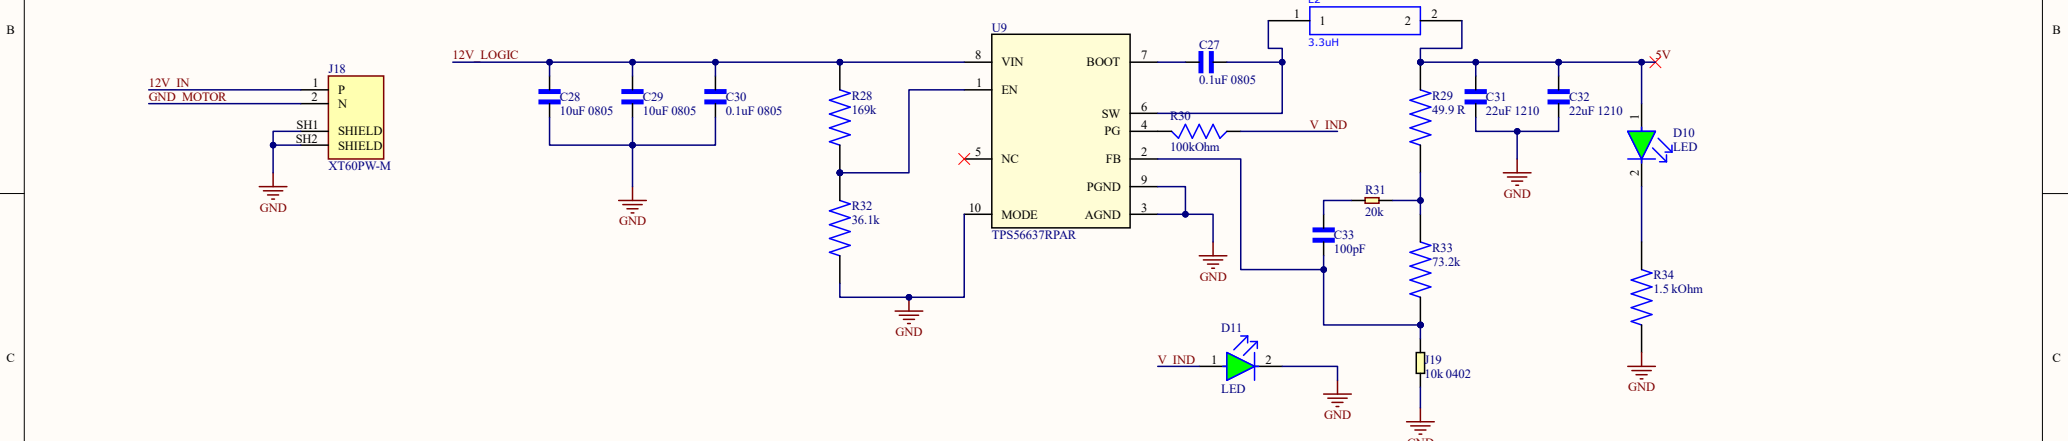
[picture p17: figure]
AGND; BOOT; 7 VIN 8; PGND; MODE 10; TPS56637RPAR; SHIELD SH1 SHIELD SH2; GND; 12V_LOGIC; GND_MOTOR; 100kOhm; LED; V_IND; D10 LED; R34 1.5 kOhm

D D

## Title

Size | Number | Revision
B
Date: | 6/19/2026 | Sheet of
File: | C:\Work\Altium\EDR\POWER.SchDoc | Drawn By:

# POWER

Add the out net from the toggle switch here , to choose in between the USB power and the power from the Buck 24 to 5 or 12 to 5

L2

## GND

## 12V_IN

## 12V_LOGIC

## 12V_MOTOR

STM32H7 Board[6A] 12V_MOTOR | 12V_MOTOR
STM32H7 Board[6B] GND_MOTOR | GND_MOTOR

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
## Fuse Mount

F2

## Fuse Mount

## Neural Nexus

02 04

Splitting the 12V line is only half the battle; you must also manage the ground return paths.

When those three motors pull 6A, that 6A has to flow back to the battery through the ground plane. If that 6A flows underneath or through the ground copper near your STM32 or your TPS56637 feedback resistors, it will raise the local ground voltage, causing your microcontroller to read false button presses, corrupt SPI data, or trigger a brown-out reset.

Do not use one massive, uniform ground pour for the whole board.

Create a specific, thick ground trace (or dedicated polygon pour) that connects the GND pins of the three TMC2209s directly back to the PGND

Keep this motor ground return path physically away from your STM32 and analog sensors.

Your logic ground (PGND and AGND from the buck converter, and the STM32 ground) should meet the motor ground at exactly one single point: the physical solder pad of the XT60's negative pin.

As a final reminder, because you are running 3 motors from this 12V line, you absolutely must place a large aluminum electrolytic capacitor (e.g., 220uF to 470uF, rated for 35V or 50V) on the 12V_MOTORS net right next to the TMC2209 drivers. Without it, the inductive flyback from three simultaneous 2A motors will easily spike the 12V rail past 30V and detonate your chips.

A A

## MicroSD_CK

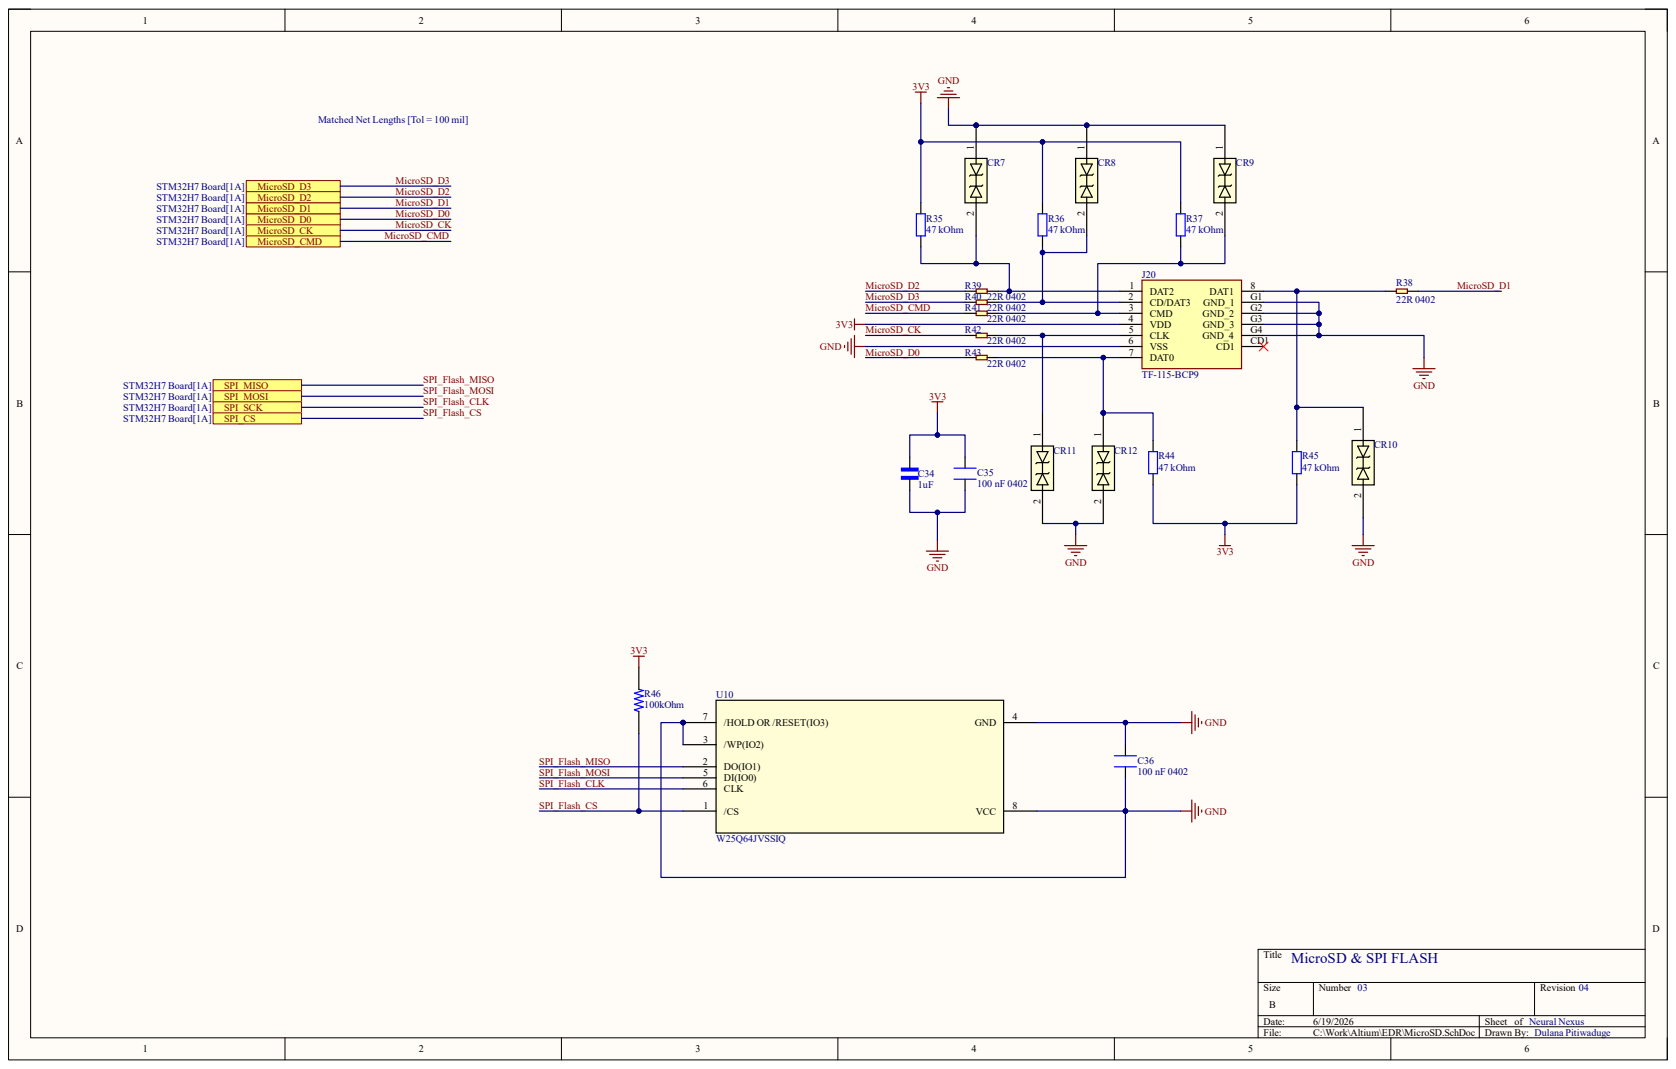
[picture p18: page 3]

Matched Net Lengths [Tol = 100 mil]

A A

## STM32H7 Board[1A] USB1_DN

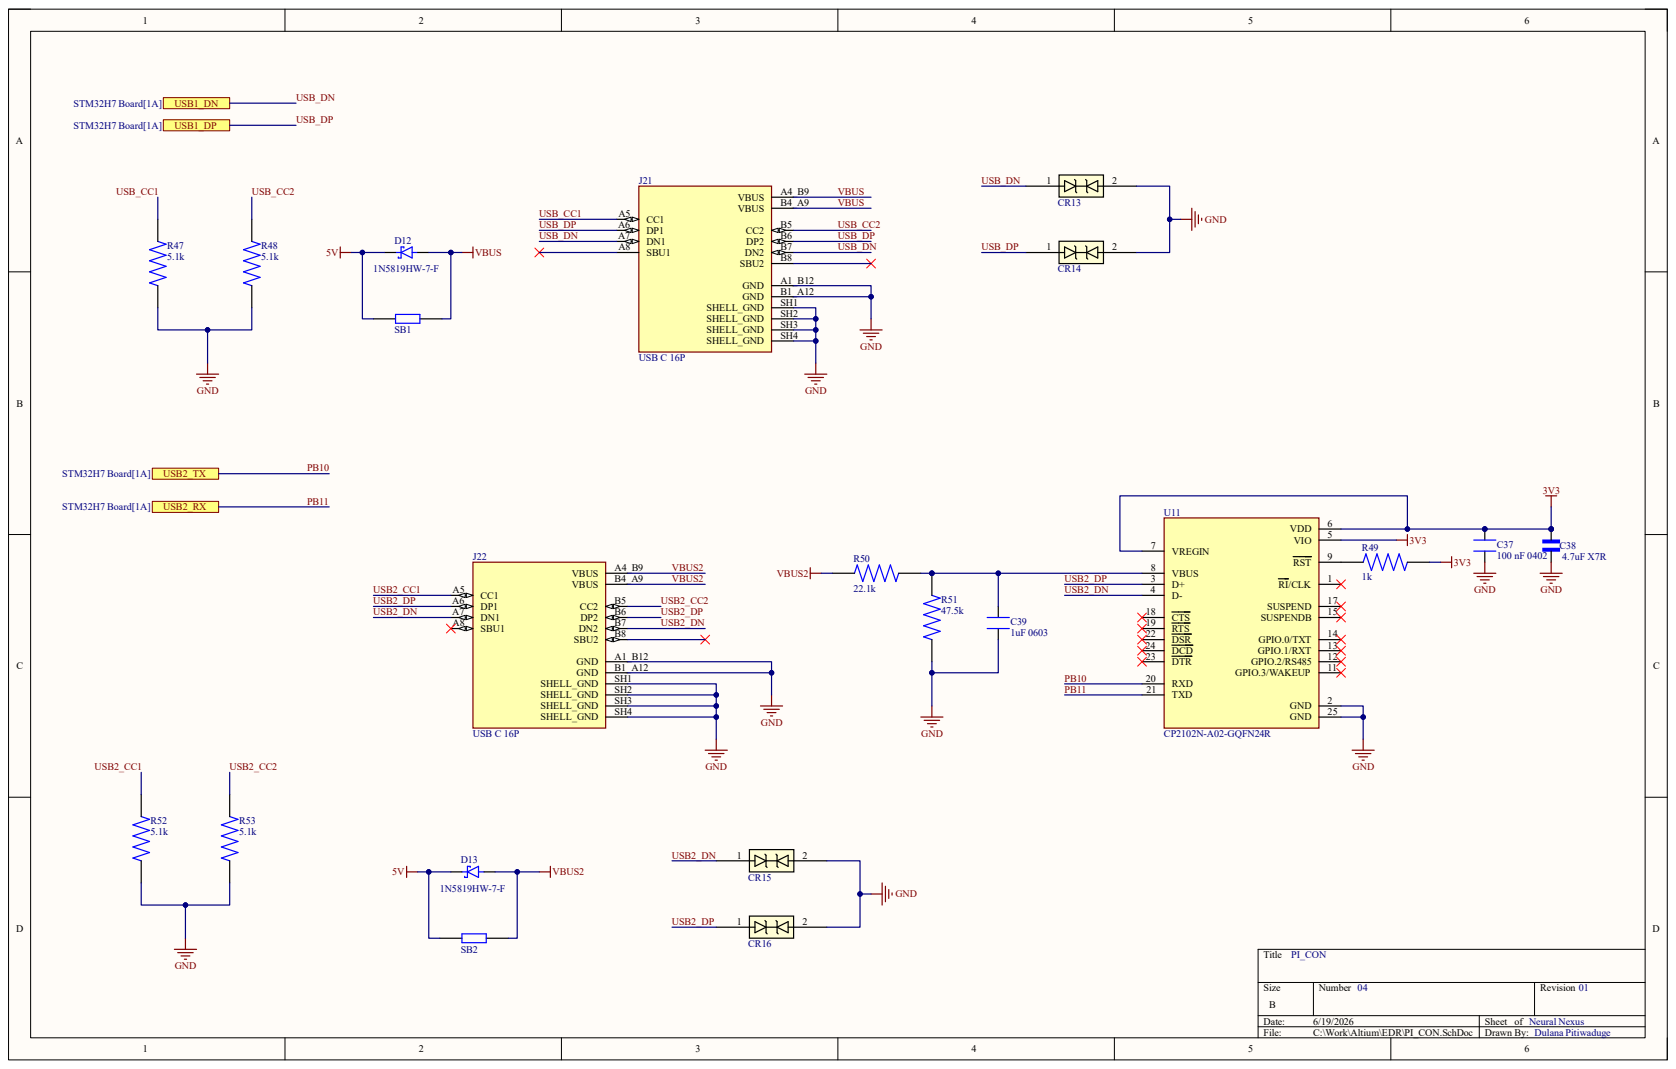
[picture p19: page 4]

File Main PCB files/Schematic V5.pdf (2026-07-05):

# SYSTEM RST

# SWITCHES

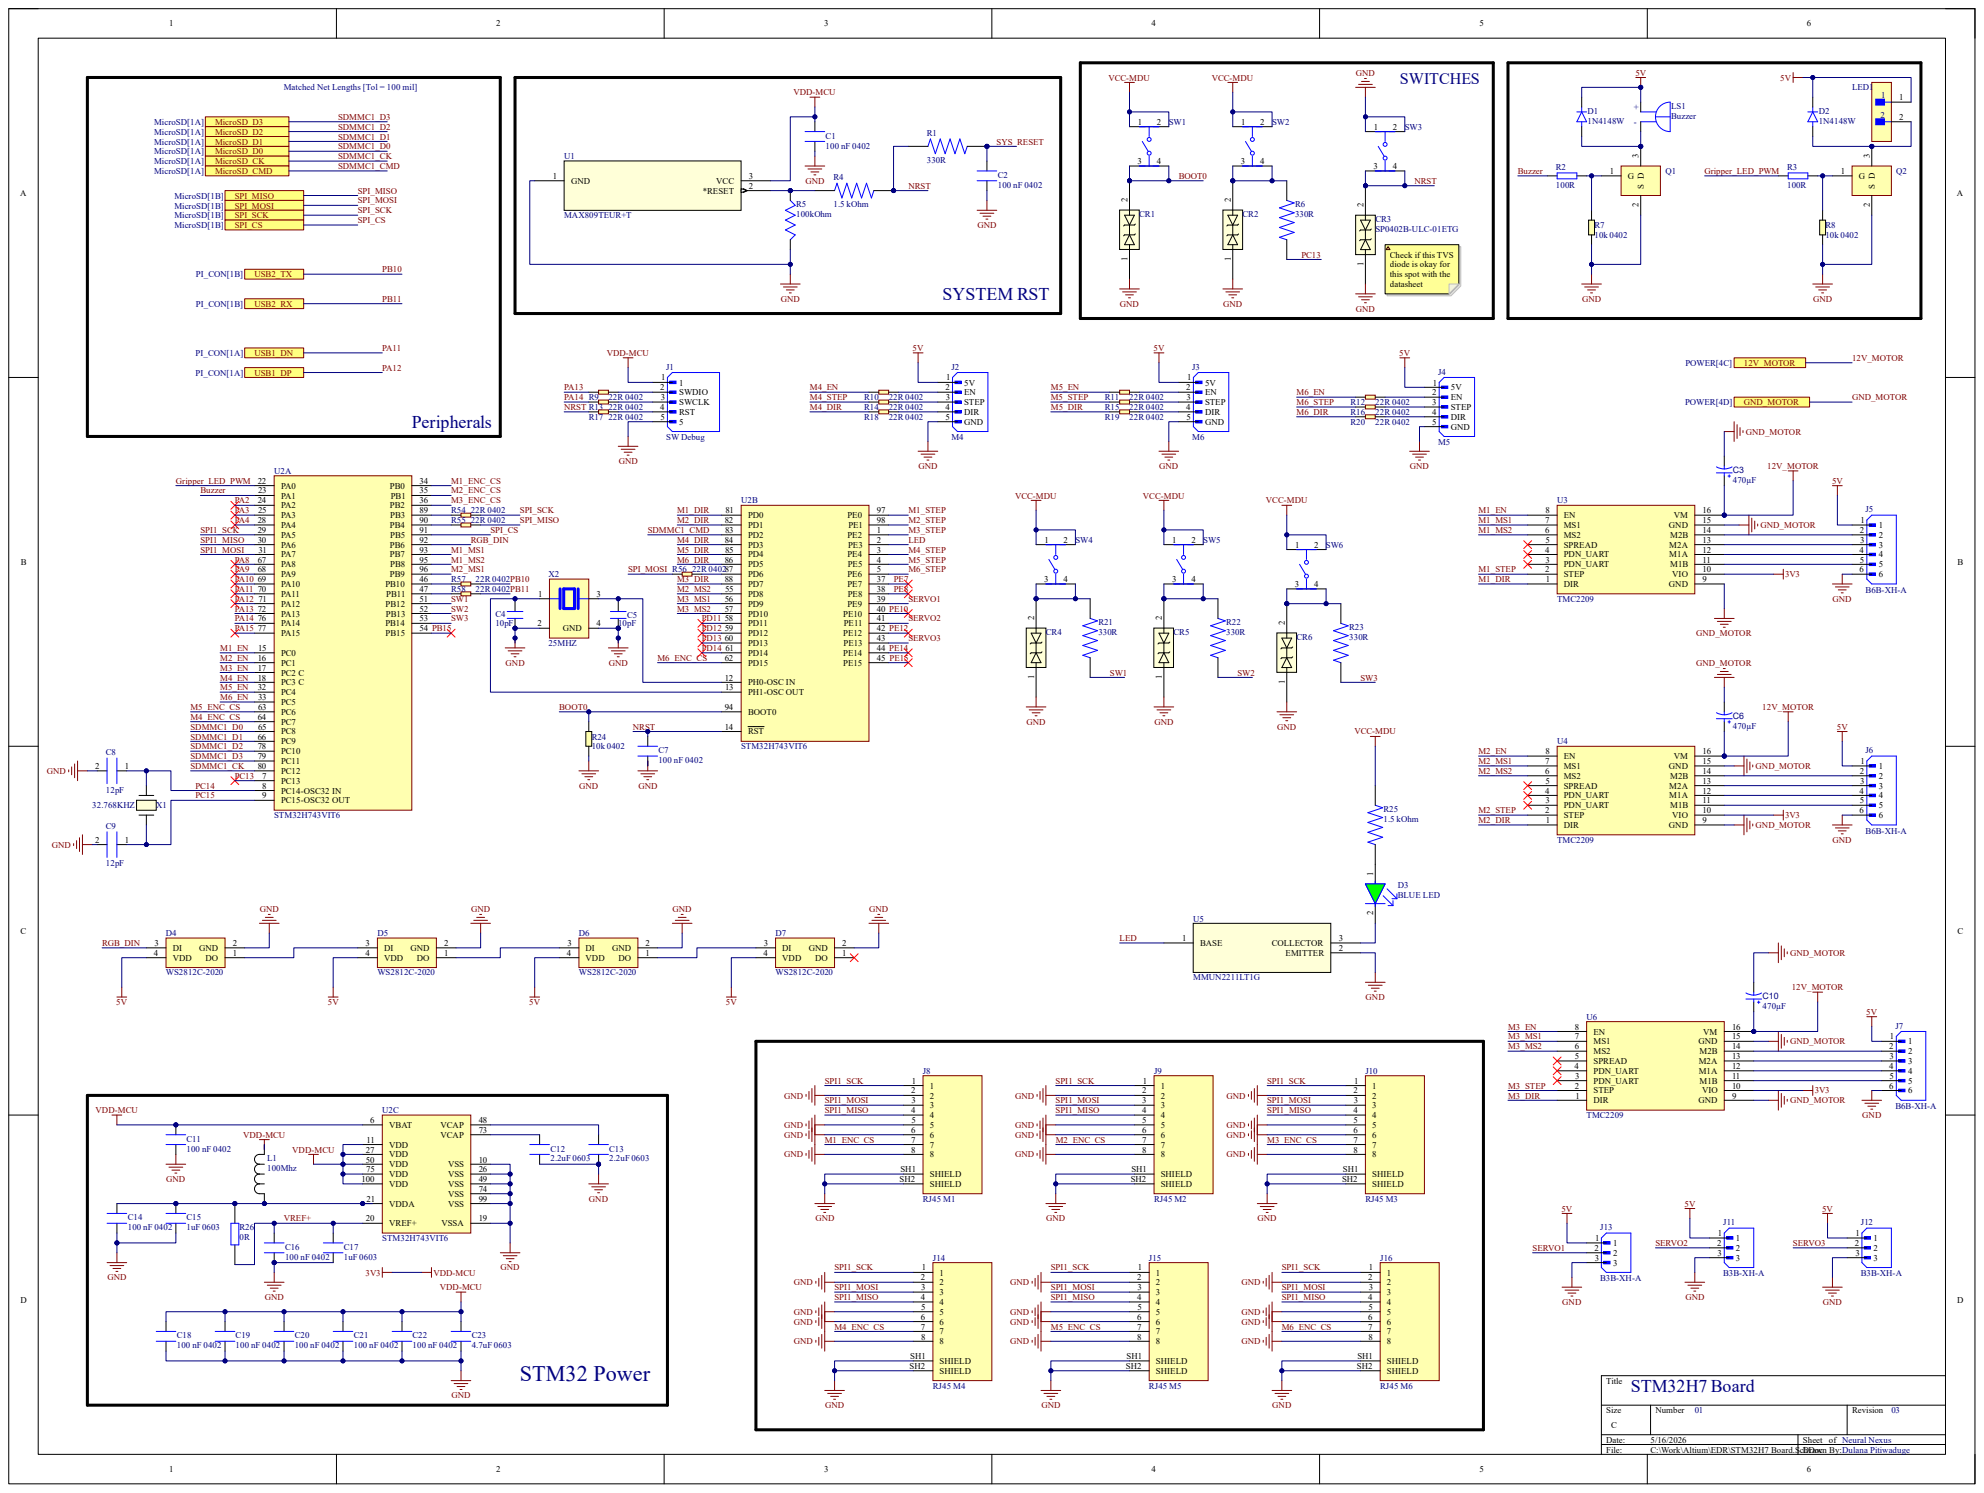
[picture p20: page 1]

Matched Net Lengths [Tol = 100 mil]

Check if this TVS
diode is okay for
this spot with the
datasheet

1

2

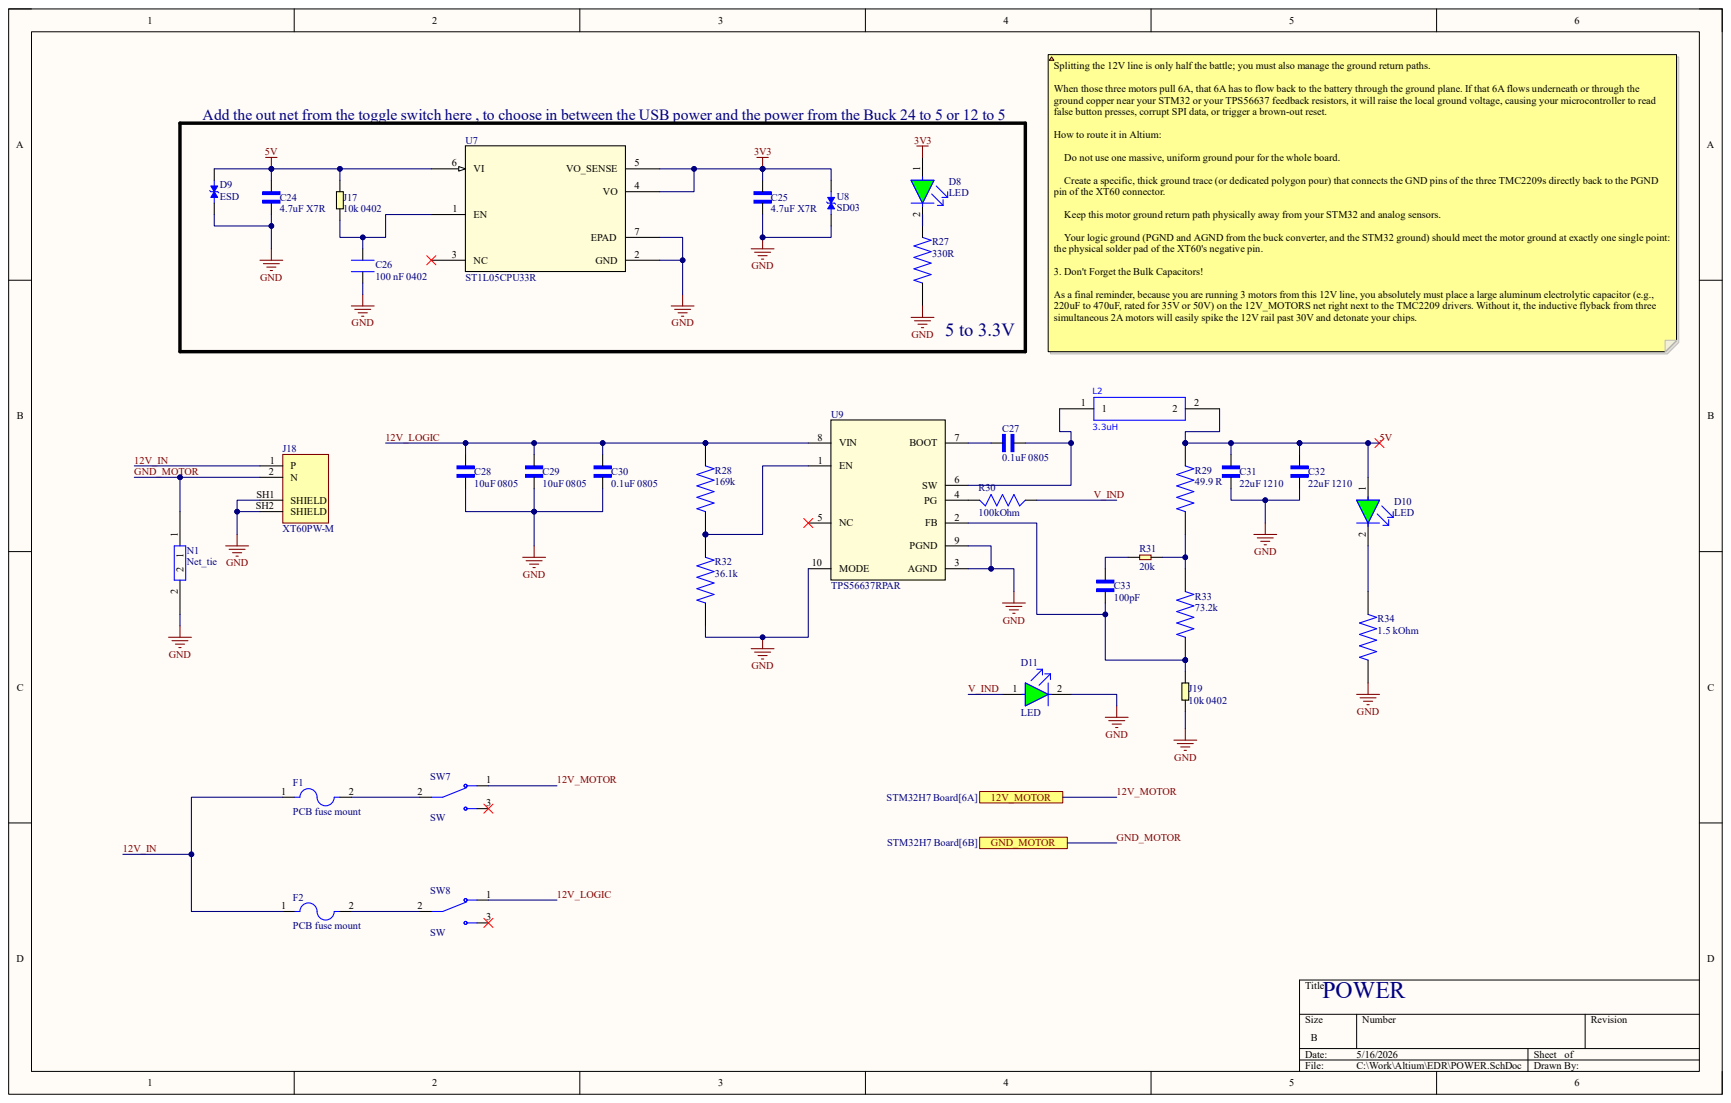
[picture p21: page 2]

Splitting the 12V line is only half the battle; you must also manage the ground return paths.

When those three motors pull 6A, that 6A has to flow back to the battery through the ground plane. If that 6A flows underneath or through the
ground copper near your STM32 or your TPS56637 feedback resistors, it will raise the local ground voltage, causing your microcontroller to read
false button presses, corrupt SPI data, or trigger a brown-out reset.

Add the out net from the toggle switch here , to choose in between the USB power and the power from the Buck 24 to 5 or 12 to 5

How to route it in Altium:

Do not use one massive, uniform ground pour for the whole board.

Create a specific, thick ground trace (or dedicated polygon pour) that connects the GND pins of the three TMC2209s directly back to the PGND
pin of the XT60 connector.

Keep this motor ground return path physically away from your STM32 and analog sensors.

Your logic ground (PGND and AGND from the buck converter, and the STM32 ground) should meet the motor ground at exactly one single point:
the physical solder pad of the XT60's negative pin.

3. Don't Forget the Bulk Capacitors!

As a final reminder, because you are running 3 motors from this 12V line, you absolutely must place a large aluminum electrolytic capacitor (e.g.,
220uF to 470uF, rated for 35V or 50V) on the 12V_MOTORS net right next to the TMC2209 drivers. Without it, the inductive flyback from three
simultaneous 2A motors will easily spike the 12V rail past 30V and detonate your chips.

1

2

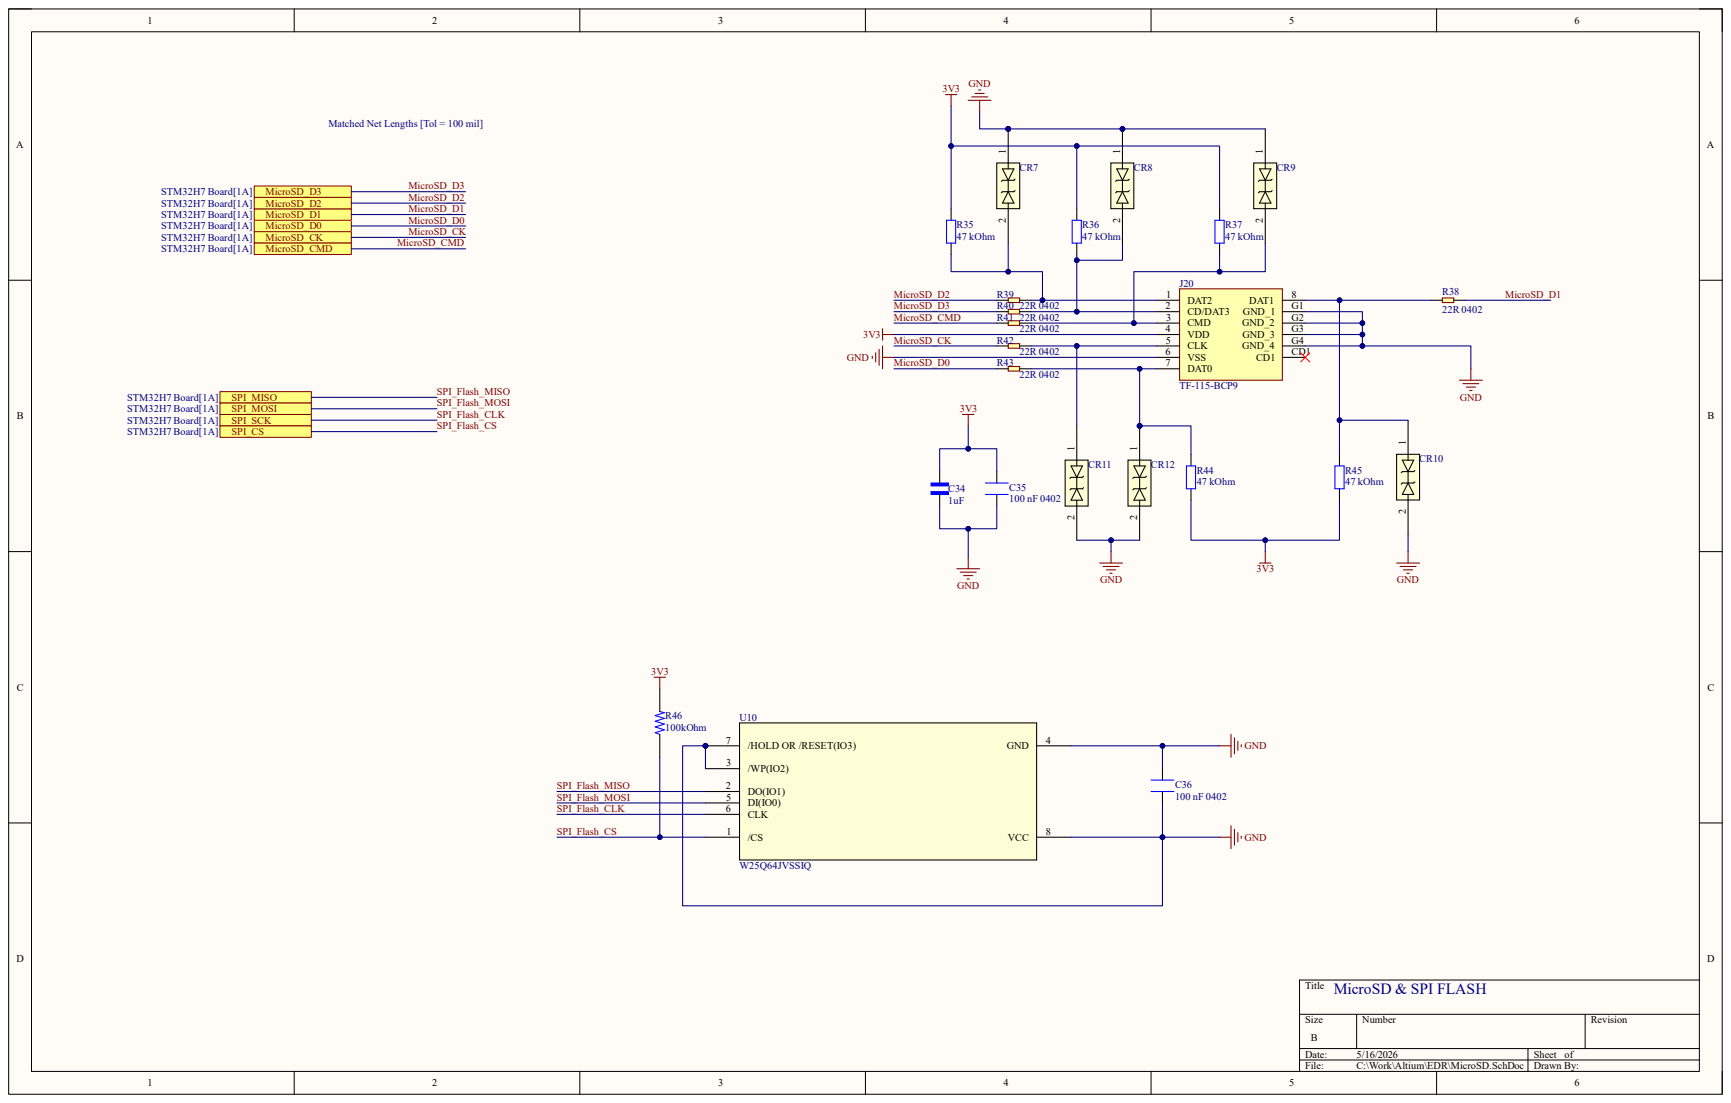
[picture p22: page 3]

Matched Net Lengths [Tol = 100 mil]

1

2

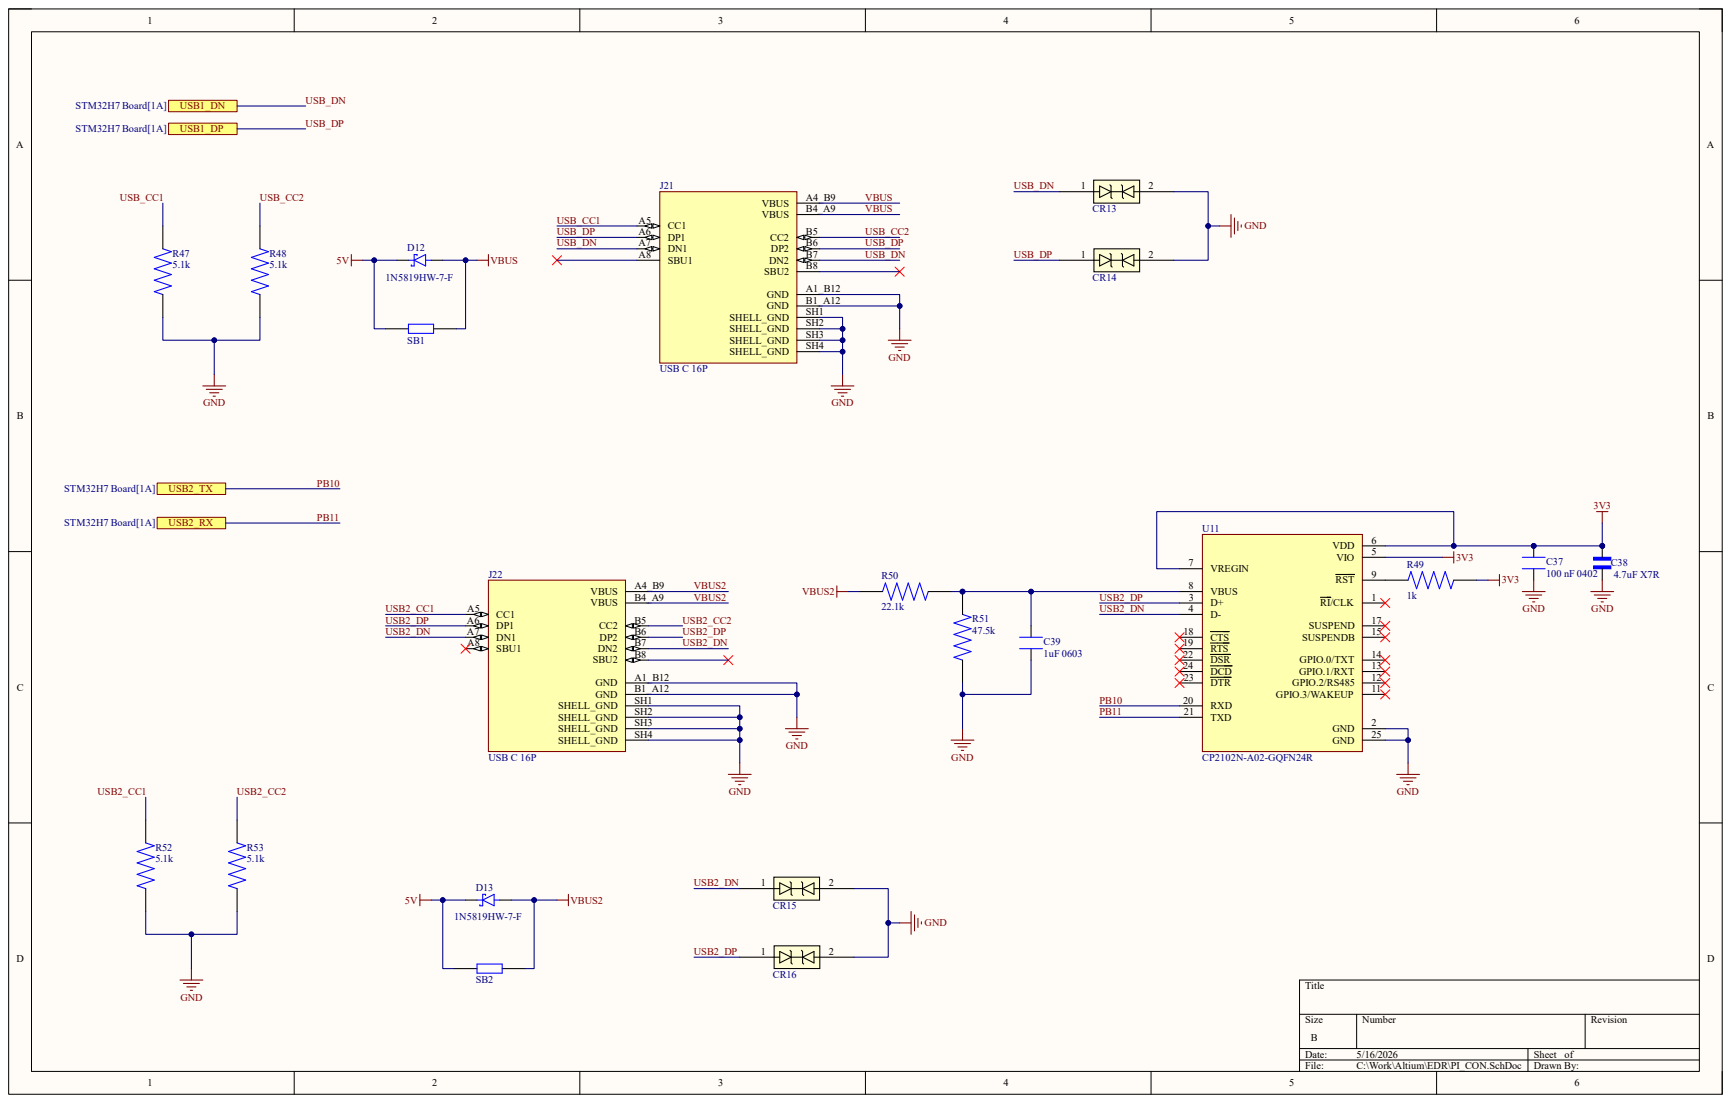
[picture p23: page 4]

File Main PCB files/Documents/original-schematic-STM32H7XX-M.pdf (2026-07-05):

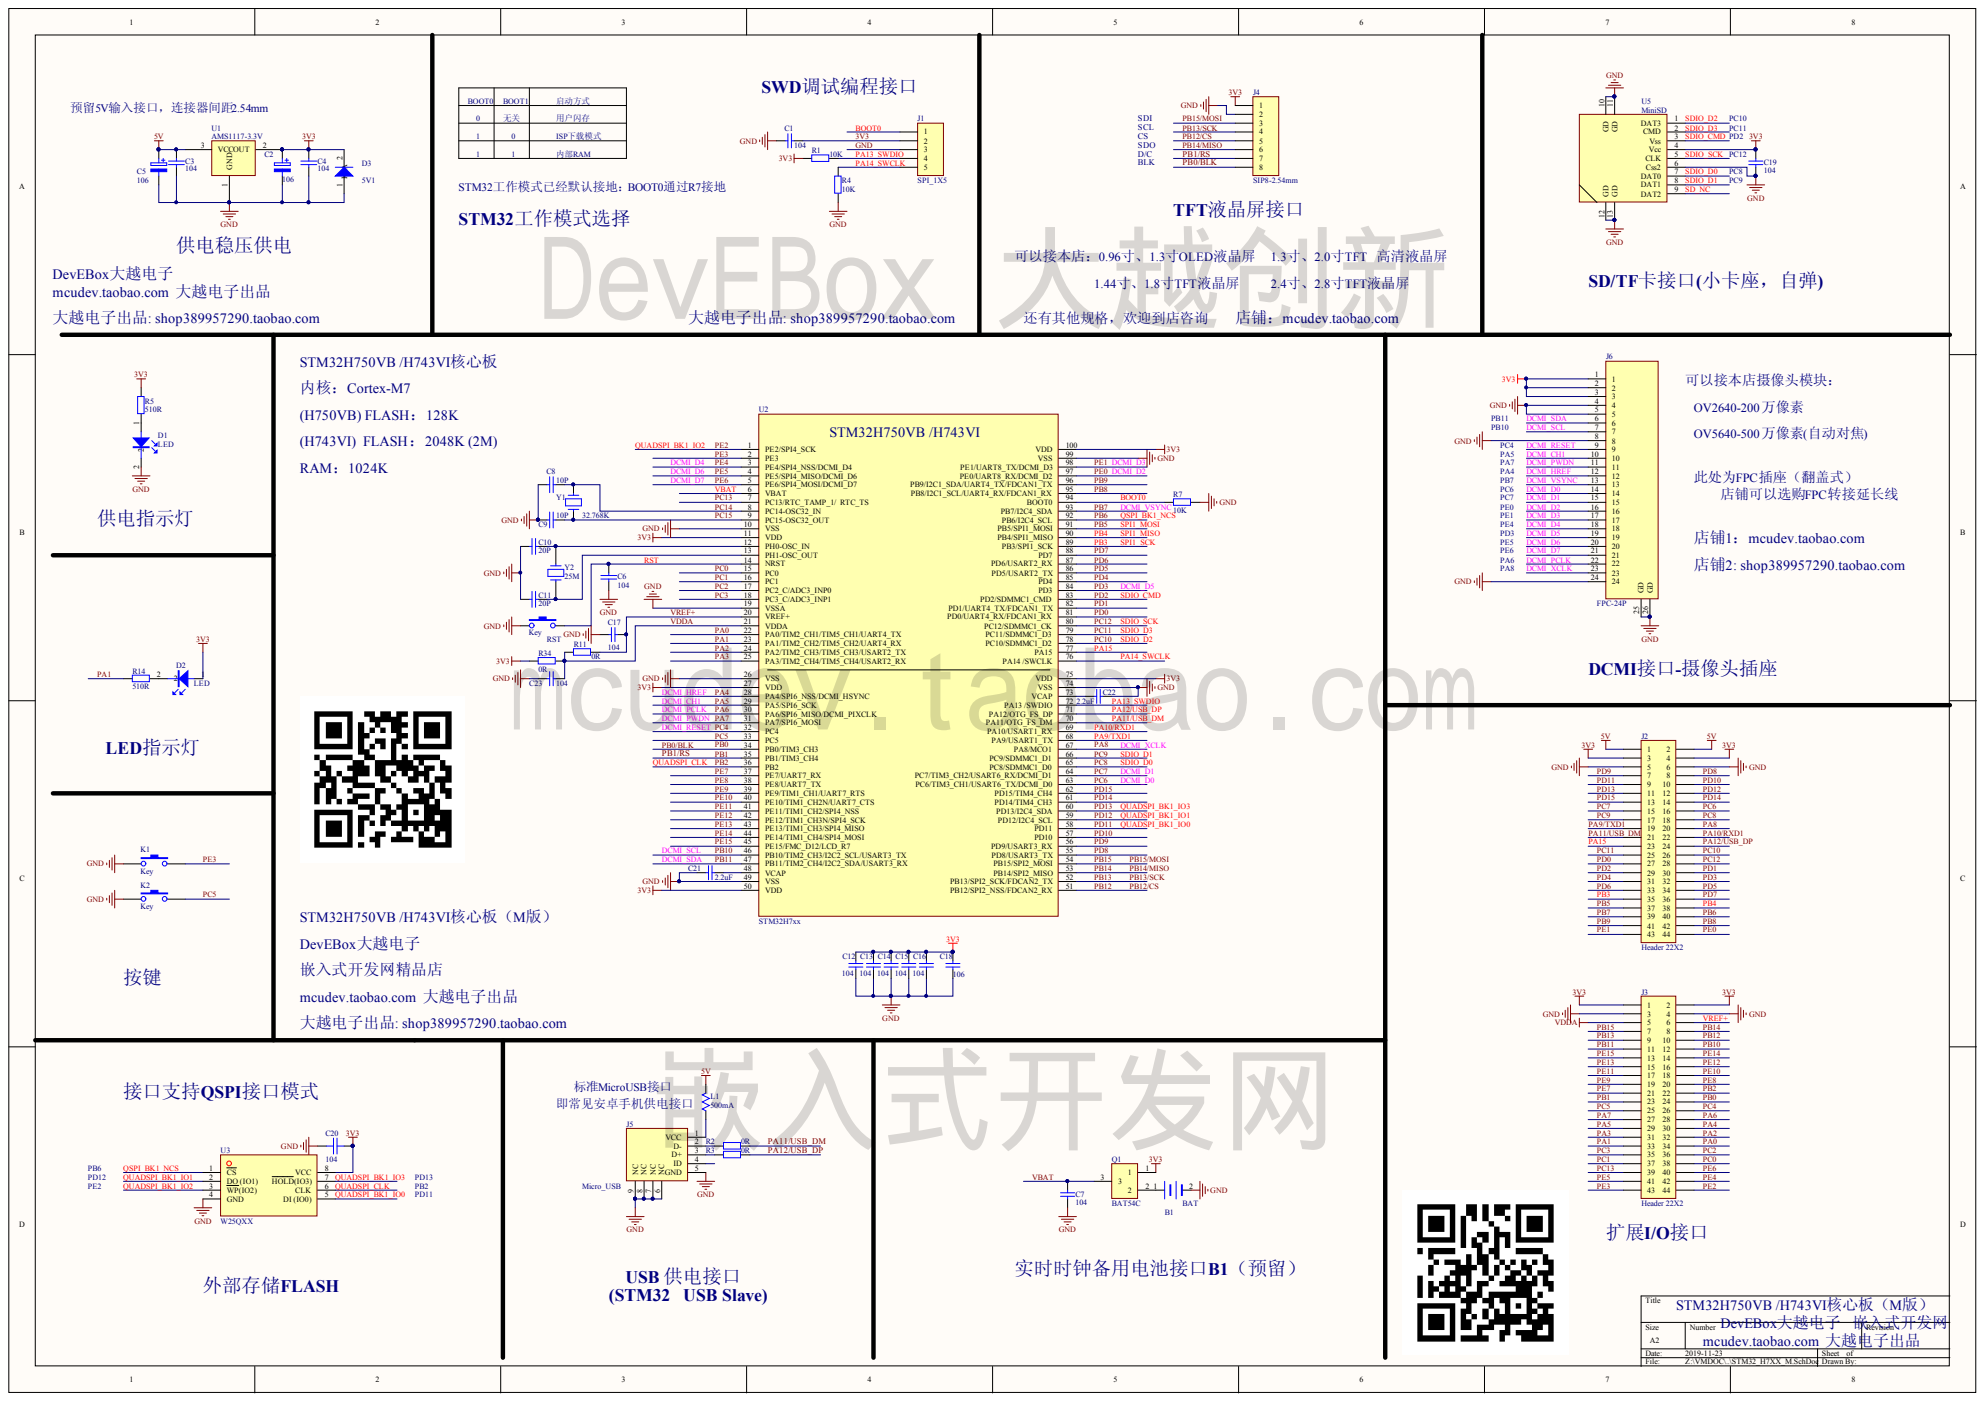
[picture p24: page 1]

GND | VSSA 19 | PD1

VCAP 48 VSS 49 | PB14

mcudev.taobao.com 大越电子出品

DevEBox大越电子

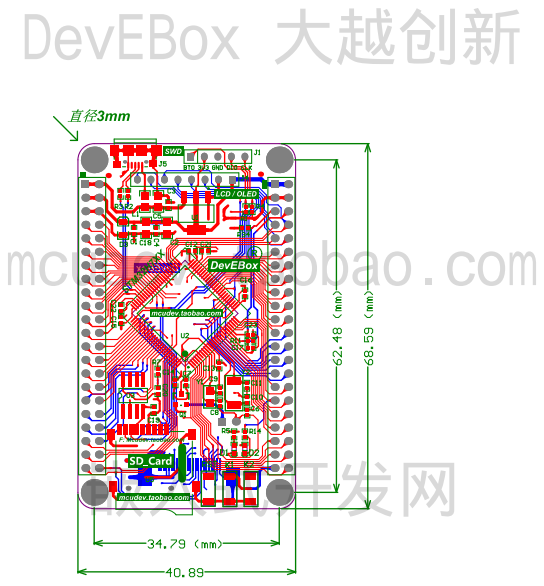
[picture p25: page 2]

Bill of Materials | <Parameter Title not found>
Source Data From: | STM32_H7XX_M.PrjPcb
Project: | | STM32_H7XX_M.PrjPcb
Variant: | | None
Creation Date: 2019-11-23 | 下午 01:44:44
Print Date: | 43792 | 43792.57279
Footprint | Comment | LibRef | Designator | Description | Quantity
SIP2-2.54mm | BAT | BATTERY | B1 | 1
RC0402 | 104 | Cap, CAP, CAP, CAP, Cap, Cap, Cap, Cap, Cap, Cap, Cap, Cap Semi, CAP, Cap | C1, C3, C4, C6, C7, C12, C13, C14, C15, C16, C17, C19, C20, C23 | Capacitor, Capacitor, Capacitor, Capacitor, Capacitor, Capacitor, Capacitor, Capacitor, Capacitor, Capacitor, Capacitor, Capacitor (Semiconductor SIM Model), [NoValue], Capacitor
14
RC0805 | 106 | ELECTRO2,
ELECTRO2,

# Cap

C2, C5, C18 | [NoValue], [NoValue], Capacitor | 3
RC0402 | 10P | CAP | C8, C9 | | 2
RC0402 | 20P | CAP | C10, C11 | Capacitor | 2
RC0603 | 2.2uF | Cap | C21, C22 | Capacitor | 2
LED-0603 | LED | LED | D1, D2 | | 2
SOD_323 | 5V1 | Diode | D3 | Default Diode | 1
SIP5-2.54mm | SPI_1X5 | Header 5H | J1 | Header, 5-Pin, Right Angle | 1
IDE2X22 | Header 22X2 | Header 22X2 | J2, J3 | Header, 22-Pin, Dual row | 2
HDR1X8 | SIP8-2.54mm | Header 8 | J4 | Header, 8-Pin | 1
micro_USB | Micro_USB | MiniUSB | J5 | | 1
FPC24- 05MM | FPC-24P | FPC-24P | J6 | | 1
SW-SPST | Key | SW-PB | K1, K2, RST | | 3
RC0805 | 500mA | RES | L1 | | 1
SOT-23- BAT54C | BAT54C | BAT54C | Q1 | | 1
RC0402 | 10K | Res2 | R1, R4, R7 | Resistor | 3
RC0402 | 0R | Res2 | R2, R3, R11, R34 | Resistor | 4
RC0402 | 510R | Res2 | R5, R14 | Resistor | 2
SOT-223 | AMS1117-3.3V | 11 | U1 | | 1
| STM32H7xx | STM32H750V | U2 | | 1
SOP8L | W25QXX | W25QXX | U3 | | 1
| MiniSD | MiniSD | U5 | | 1
JZ3215-32K | 32.768K | CRYSTAL | Y1 | 晶振 | 1
JZ5032-8M | 25M | CRYSTAL | Y2 | Crystal | 1
| | | | | 53
Approved | | Notes

# DevEBox 大越创新

# mcudev.taobao.com

# 嵌入式开发网

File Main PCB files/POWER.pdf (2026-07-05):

# SYSTEM RST

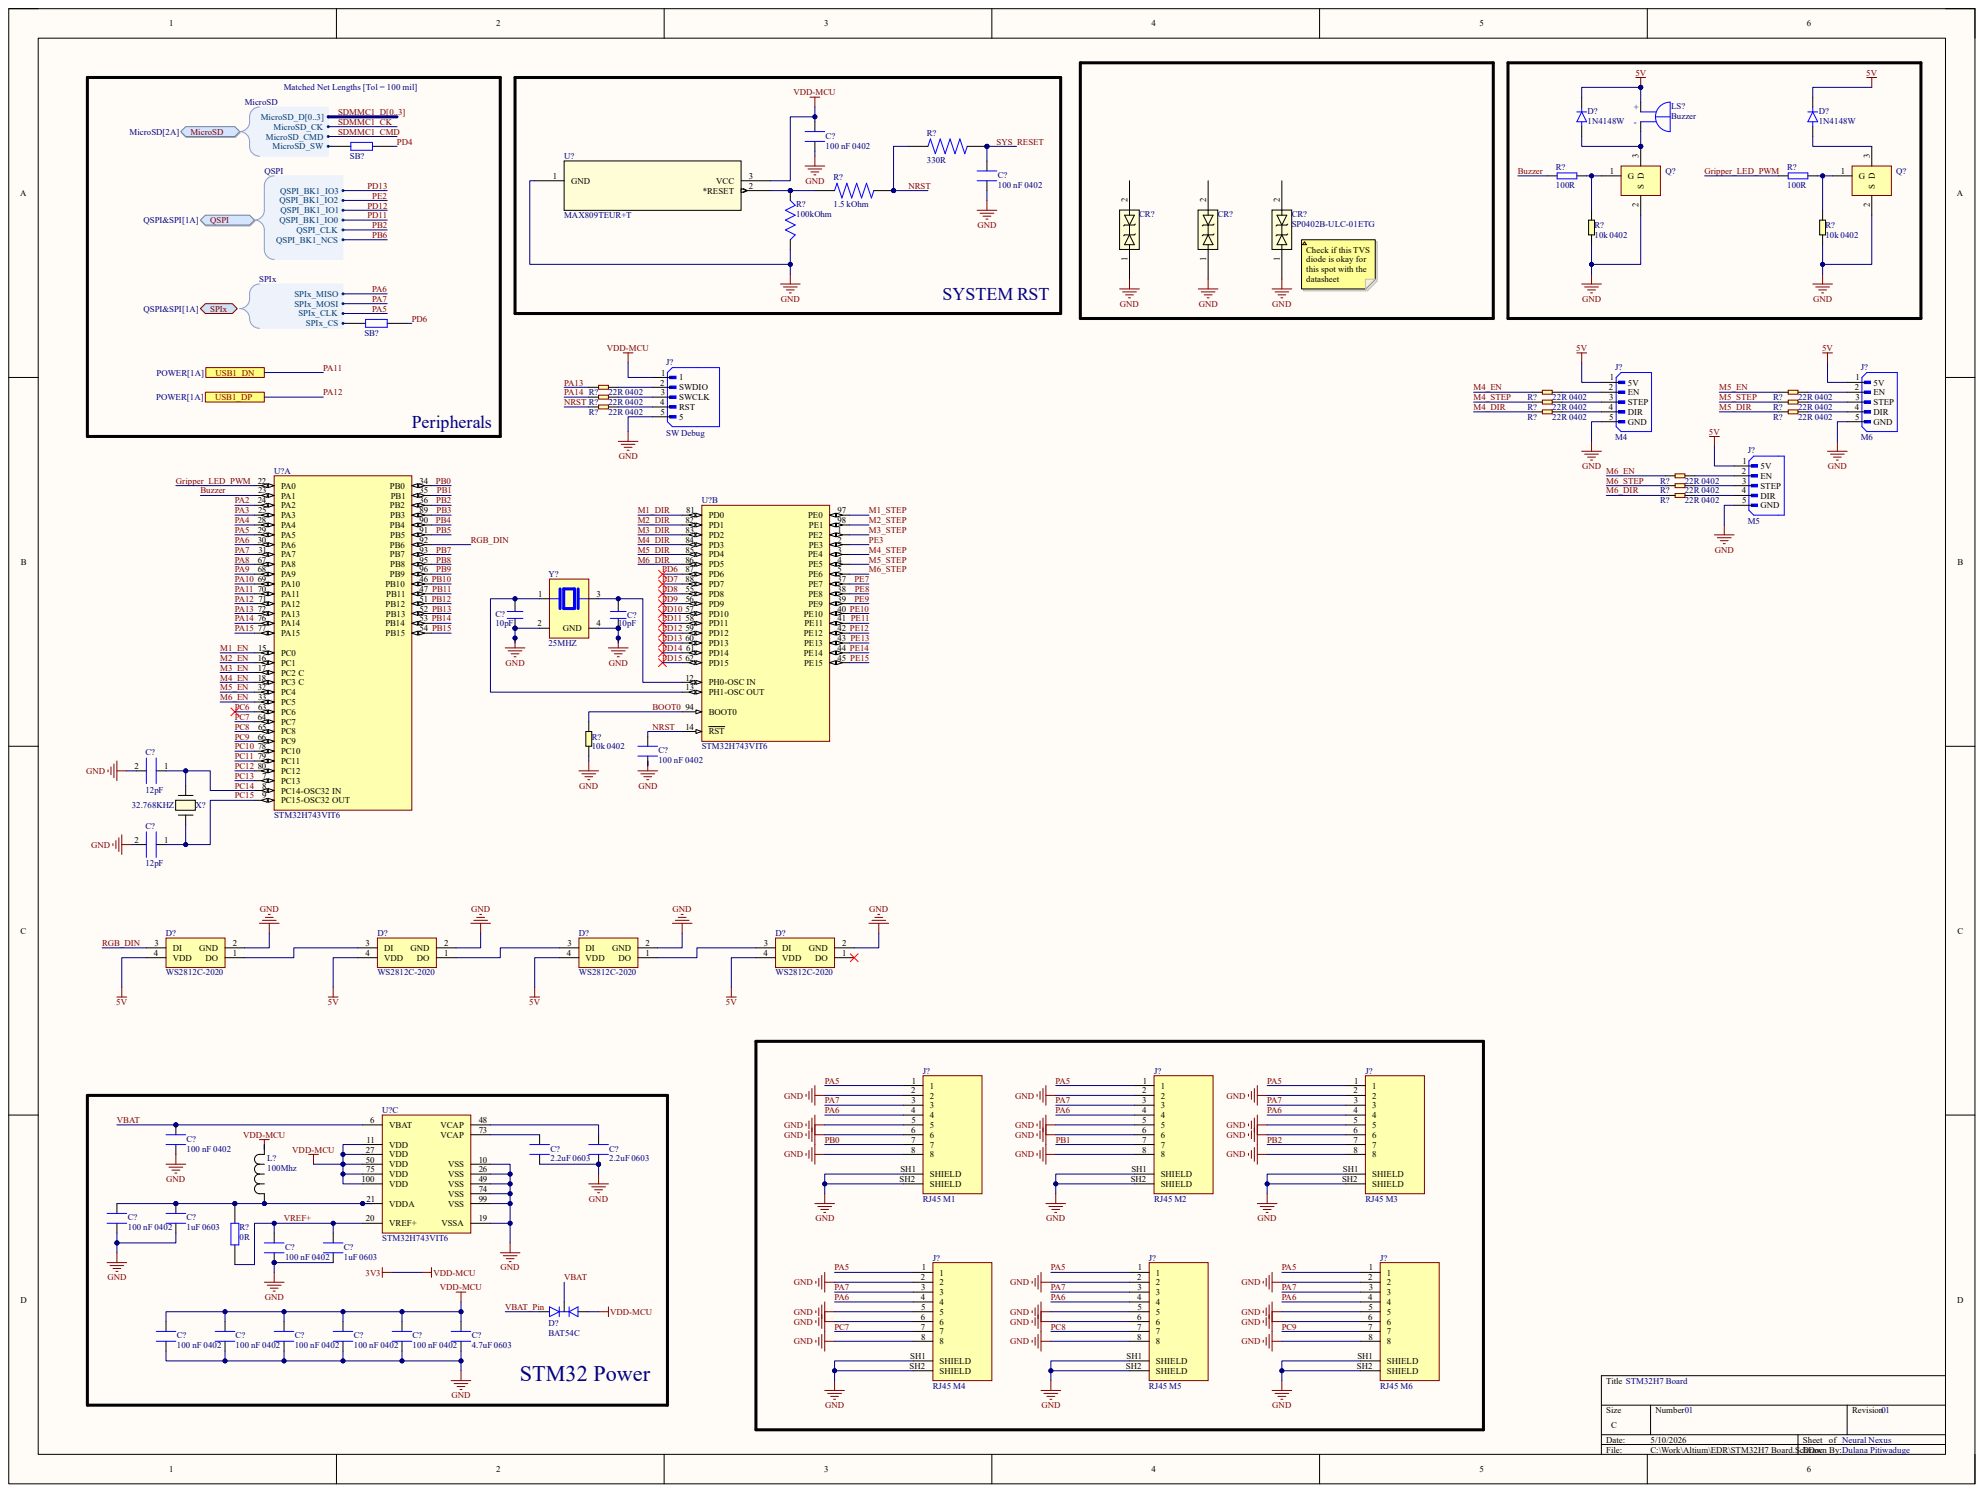
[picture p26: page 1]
Title; Size; Number; Revision; Date:; Sheet of; File:; C:\Work\Altium\EDR\STM32H7 Board.SchDoc Drawn By:; PC0 15 PC1 16 PC2 C 17 PC3 C 18 PC4 32 PC5 33 PC6 63 PC7 64 PC8 65 PC9 66 PC10 78 PC11 79 PC12 80 PC13 7 PC14-OSC32 IN 8 PC15-OSC32 OUT 9; STM32H743VIT6; PH0-OSC IN 12 PH1-OSC OUT 13; RST 14; BOOT0 94; VDD 11 VDD 27 VDD 50 VDD 75 VDD 100; VDDA 21; VCAP; 73 VBAT 6; VREF+ 20; VSS; VSSA; STM32H7 Board; Neural Nexus Dulana Pitiwaduge; GND; 25MHZ; CR? SP0402B-ULC-01ETG; GND 1; *RESET; VCC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

Matched Net Lengths [Tol = 100 mil]

QSPI&SPI[1A] QSPI

Check if this TVS
diode is okay for
this spot with the
datasheet

QSPI&SPI[1A] SPIx

1

2

Title; Size; Number; Revision; Date:; Sheet of; File:; C:\Work\Altium\EDR\POWER.SchDoc; Drawn By:; POWER; GND; ESD; STM32H7 Board[1A] USB1_DN; STM32H7 Board[1B] USB1_DP; USB_DN; USB_DP; CC1 A5 DP1 A6 DN1 A7 SBU1 A8; VBUS; SBU2; SHELL_GND; USB C 16P; VBUS VBUS; USB_CC1; USB_CC2; VO_SENSE; EPAD; ST1L05CPU33R; AGND; BOOT; 7 VIN 8; PGND; MODE 10; TPS56637RPAR; SHIELD SH1 SHIELD SH2; 12V_IN_GND; D? LED; 100kOhm; LED; VCC

Add the out net from the toggle switch here , to choose in between the USB power and the power from the Buck 24 to 5 or 12 to 5

1

2

Title; Size; Number; Revision; Date:; Sheet of; File:; C:\Work\Altium\EDR\MicroSD.SchDoc; Drawn By:; MicroSD; STM32H7 Board[1A] MicroSD; MicroSD_D[0..3] MicroSD_CK MicroSD_CMD MicroSD_SW; MIcroSD_D[0..3] MicroSD_CK MicroSD_CMD MicroSD_SW; Matched Net Lengths [Tol = 100 mil]; DAT2 1 CD/DAT3 2 CMD 3 VDD 4 CLK 5 VSS 6 DAT0 7; DAT1; GND_1; GND_2; GND_3; GND_4; TF-115-BCP9; GND; R? 47 kOhm; R? 47 kOhm 1 2; 47 kOhm 1 2; GND 1 2; MicroSD_SW; MicroSD_D0; MicroSD_D2; MicroSD_D1; MicroSD_D3 MicroSD_CMD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

1

2

Size; Number; Revision; Date:; Sheet of; File:; C:\Work\Altium\EDR\QSPI&SPI.SchDoc Drawn By:; STM32H7 Board[1A] QSPI; QSPI_BK1_IO3; QSPI_BK1_IO0; QSPI_BK1_IO1; QSPI_BK1_IO2; QSPI_BK1_NCS; QSPI_CLK; QSPI; STM32H7 Board[1A] SPIx; SPIx_MISO SPIx_MOSI SPIx_CLK SPIx_CS; SPIx; CLK 6; VCC; GND; W25Q64JVSSIQ; 33 Ohms; R? 100kOhm; SPI_Flash_MISO; SPI_Flash_MISO SPI_Flash_MOSI; SPI_Flash_MOSI SPI_Flash_CLK; SPI_Flash_CLK SPI_Flash_CS; SPI_Flash_CS

/HOLD OR /RESET(IO3) 7

Title
QSPI&SPI FLASH

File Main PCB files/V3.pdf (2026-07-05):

# SYSTEM RST

# SWITCHES


Matched Net Lengths [Tol = 100 mil]

Check if this TVS
diode is okay for
this spot with the
datasheet

1

2


Splitting the 12V line is only half the battle; you must also manage the ground return paths.

When those three motors pull 6A, that 6A has to flow back to the battery through the ground plane. If that 6A flows underneath or through the
ground copper near your STM32 or your TPS56637 feedback resistors, it will raise the local ground voltage, causing your microcontroller to read
false button presses, corrupt SPI data, or trigger a brown-out reset.

Add the out net from the toggle switch here , to choose in between the USB power and the power from the Buck 24 to 5 or 12 to 5

How to route it in Altium:

Do not use one massive, uniform ground pour for the whole board.

Create a specific, thick ground trace (or dedicated polygon pour) that connects the GND pins of the three TMC2209s directly back to the PGND
pin of the XT60 connector.

Keep this motor ground return path physically away from your STM32 and analog sensors.

Your logic ground (PGND and AGND from the buck converter, and the STM32 ground) should meet the motor ground at exactly one single point:
the physical solder pad of the XT60's negative pin.

3. Don't Forget the Bulk Capacitors!

As a final reminder, because you are running 3 motors from this 12V line, you absolutely must place a large aluminum electrolytic capacitor (e.g.,
220uF to 470uF, rated for 35V or 50V) on the 12V_MOTORS net right next to the TMC2209 drivers. Without it, the inductive flyback from three
simultaneous 2A motors will easily spike the 12V rail past 30V and detonate your chips.

1

2


Matched Net Lengths [Tol = 100 mil]

1

2


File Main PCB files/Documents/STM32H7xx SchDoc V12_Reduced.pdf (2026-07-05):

# SYSTEM RST


A | A

U2


11

22


11

22

Size; umb; Rev; 4-MicroSD; MicroSD; icro; Micro; ESD; CMD; VSS; Matched; Net; Len; lerance =; Protecti

11

22

Size; umb; Rev; 5-QSPI.; nCS; VCC; QSPI_BK; QSPI_CL; QSPI; Matched; Net; Len; lerance =; Default; MBit; 3 SPI_Flash_CS; SPI_Flas; SPIx; _MIS

QSPI&SPI Flash

11

22

Size; umb; Rev; 6-TFT-LCD; DLCD; LCD; VCC; _SCL LCD; _RESE; TFT-L; 0.96'' TFT-LCD; 3LCD; TLCD; PIN; 3 FPC0.5-SMT; _SCL


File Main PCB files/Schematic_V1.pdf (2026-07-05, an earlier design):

# SYSTEM RST

Title; Size; Number; Revision; Date:; Sheet of; File:; C:\Work\Altium\EDR\STM32H7 Board.SchDoc Drawn By:; PC0 15 PC1 16 PC2 C 17 PC3 C 18 PC4 32 PC5 33 PC6 63 PC7 64 PC8 65 PC9 66 PC10 78 PC11 79 PC12 80 PC13 7 PC14-OSC32 IN 8 PC15-OSC32 OUT 9; STM32H743VIT6; PH0-OSC IN 12 PH1-OSC OUT 13; RST 14; BOOT0 94; VDD 11 VDD 27 VDD 50 VDD 75 VDD 100; VDDA 21; VCAP; 73 VBAT 6; VREF+ 20; VSS; VSSA; STM32H7 Board; Neural Nexus Dulana Pitiwaduge; GND; 25MHZ; CR? SP0402B-ULC-01ETG; GND 1; *RESET; VCC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

Matched Net Lengths [Tol = 100 mil]

QSPI&SPI[1A] QSPI

Check if this TVS
diode is okay for
this spot with the
datasheet

QSPI&SPI[1A] SPIx

1

2

Title; Size; Number; Revision; Date:; Sheet of; File:; C:\Work\Altium\EDR\POWER.SchDoc; Drawn By:; POWER; GND; ESD; STM32H7 Board[1A] USB1_DN; STM32H7 Board[1B] USB1_DP; USB_DN; USB_DP; CC1 A5 DP1 A6 DN1 A7 SBU1 A8; VBUS; SBU2; SHELL_GND; USB C 16P; VBUS VBUS; USB_CC1; USB_CC2; VO_SENSE; EPAD; ST1L05CPU33R; AGND; BOOT; 7 VIN 8; PGND; MODE 10; TPS56637RPAR; SHIELD SH1 SHIELD SH2; 12V_IN_GND; D? LED; 100kOhm; LED; VCC

Add the out net from the toggle switch here , to choose in between the USB power and the power from the Buck 24 to 5 or 12 to 5

1

2

Title; Size; Number; Revision; Date:; Sheet of; File:; C:\Work\Altium\EDR\MicroSD.SchDoc; Drawn By:; MicroSD; STM32H7 Board[1A] MicroSD; MicroSD_D[0..3] MicroSD_CK MicroSD_CMD MicroSD_SW; MIcroSD_D[0..3] MicroSD_CK MicroSD_CMD MicroSD_SW; Matched Net Lengths [Tol = 100 mil]; DAT2 1 CD/DAT3 2 CMD 3 VDD 4 CLK 5 VSS 6 DAT0 7; DAT1; GND_1; GND_2; GND_3; GND_4; TF-115-BCP9; GND; R? 47 kOhm; R? 47 kOhm 1 2; 47 kOhm 1 2; GND 1 2; MicroSD_SW; MicroSD_D0; MicroSD_D2; MicroSD_D1; MicroSD_D3 MicroSD_CMD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

1

2

Size; Number; Revision; Date:; Sheet of; File:; C:\Work\Altium\EDR\QSPI&SPI.SchDoc Drawn By:; STM32H7 Board[1A] QSPI; QSPI_BK1_IO3; QSPI_BK1_IO0; QSPI_BK1_IO1; QSPI_BK1_IO2; QSPI_BK1_NCS; QSPI_CLK; QSPI; STM32H7 Board[1A] SPIx; SPIx_MISO SPIx_MOSI SPIx_CLK SPIx_CS; SPIx; CLK 6; VCC; GND; W25Q64JVSSIQ; 33 Ohms; R? 100kOhm; SPI_Flash_MISO; SPI_Flash_MISO SPI_Flash_MOSI; SPI_Flash_MOSI SPI_Flash_CLK; SPI_Flash_CLK SPI_Flash_CS; SPI_Flash_CS

/HOLD OR /RESET(IO3) 7

Title
QSPI&SPI FLASH

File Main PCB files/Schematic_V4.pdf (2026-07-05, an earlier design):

# SYSTEM RST

# SWITCHES


Matched Net Lengths [Tol = 100 mil]

Check if this TVS
diode is okay for
this spot with the
datasheet

1

2


Splitting the 12V line is only half the battle; you must also manage the ground return paths.

When those three motors pull 6A, that 6A has to flow back to the battery through the ground plane. If that 6A flows underneath or through the
ground copper near your STM32 or your TPS56637 feedback resistors, it will raise the local ground voltage, causing your microcontroller to read
false button presses, corrupt SPI data, or trigger a brown-out reset.

Add the out net from the toggle switch here , to choose in between the USB power and the power from the Buck 24 to 5 or 12 to 5

How to route it in Altium:

Do not use one massive, uniform ground pour for the whole board.

Create a specific, thick ground trace (or dedicated polygon pour) that connects the GND pins of the three TMC2209s directly back to the PGND
pin of the XT60 connector.

Keep this motor ground return path physically away from your STM32 and analog sensors.

Your logic ground (PGND and AGND from the buck converter, and the STM32 ground) should meet the motor ground at exactly one single point:
the physical solder pad of the XT60's negative pin.

3. Don't Forget the Bulk Capacitors!

As a final reminder, because you are running 3 motors from this 12V line, you absolutely must place a large aluminum electrolytic capacitor (e.g.,
220uF to 470uF, rated for 35V or 50V) on the 12V_MOTORS net right next to the TMC2209 drivers. Without it, the inductive flyback from three
simultaneous 2A motors will easily spike the 12V rail past 30V and detonate your chips.

1

2


Matched Net Lengths [Tol = 100 mil]

1

2


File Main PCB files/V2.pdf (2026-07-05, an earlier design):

## SYSTEM RST

## SWITCHES

Title; Size; Number; Revision; Date:; Sheet of; File:; C:\Work\Altium\EDR\STM32H7 Board.SchDoc Drawn By:; PC0 15 PC1 16 PC2 C 17 PC3 C 18 PC4 32 PC5 33 PC6 63 PC7 64 PC8 65 PC9 66 PC10 78 PC11 79 PC12 80 PC13 7 PC14-OSC32 IN 8 PC15-OSC32 OUT 9; STM32H743VIT6; PH0-OSC IN 12 PH1-OSC OUT 13; RST 14; BOOT0 94; VDD 11 VDD 27 VDD 50 VDD 75 VDD 100; VDDA 21; VCAP; 73 VBAT 6; VREF+ 20; VSS; VSSA; STM32H7 Board; Neural Nexus Dulana Pitiwaduge; GND; 25MHZ; CR? SP0402B-ULC-01ETG; GND 1; *RESET; VCC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

Matched Net Lengths [Tol = 100 mil]

QSPI&SPI[1A] QSPI

Check if this TVS
diode is okay for
this spot with the
datasheet

QSPI&SPI[1A] SPIx

Add the out net from the toggle switch here , to choose in between the USB power and the power from the Buck 24 to 5 or 12 to 5

Title; Size; Number; Revision; Date:; Sheet of; File:; C:\Work\Altium\EDR\POWER.SchDoc; Drawn By:; POWER; GND; ESD; VO_SENSE; EPAD; ST1L05CPU33R; AGND; BOOT; 7 VIN 8; PGND; MODE 10; TPS56637RPAR; SHIELD SH1 SHIELD SH2; 12V_LOGIC; GND_MOTOR; D? LED; 100kOhm; LED; VCC; 10A 32V FUSE; PCB fuse mount; 12V_MOTOR

Splitting the 12V line is only half the battle; you must also manage the ground return paths.

When those three motors pull 6A, that 6A has to flow back to the battery through the ground plane. If that 6A flows underneath or through the
ground copper near your STM32 or your TPS56637 feedback resistors, it will raise the local ground voltage, causing your microcontroller to read
false button presses, corrupt SPI data, or trigger a brown-out reset.

How to route it in Altium:

Do not use one massive, uniform ground pour for the whole board.

Create a specific, thick ground trace (or dedicated polygon pour) that connects the GND pins of the three TMC2209s directly back to the PGND
pin of the XT60 connector.

Keep this motor ground return path physically away from your STM32 and analog sensors.

Your logic ground (PGND and AGND from the buck converter, and the STM32 ground) should meet the motor ground at exactly one single point:
the physical solder pad of the XT60's negative pin.

3. Don't Forget the Bulk Capacitors!

As a final reminder, because you are running 3 motors from this 12V line, you absolutely must place a large aluminum electrolytic capacitor (e.g.,
220uF to 470uF, rated for 35V or 50V) on the 12V_MOTORS net right next to the TMC2209 drivers. Without it, the inductive flyback from three
simultaneous 2A motors will easily spike the 12V rail past 30V and detonate your chips.

Title; Size; Number; Revision; Date:; Sheet of; File:; C:\Work\Altium\EDR\MicroSD.SchDoc; Drawn By:; MicroSD; STM32H7 Board[1A] MicroSD; MicroSD_D[0..3] MicroSD_CK MicroSD_CMD MicroSD_SW; MIcroSD_D[0..3] MicroSD_CK MicroSD_CMD MicroSD_SW; Matched Net Lengths [Tol = 100 mil]; DAT2 1 CD/DAT3 2 CMD 3 VDD 4 CLK 5 VSS 6 DAT0 7; DAT1; GND_1; GND_2; GND_3; GND_4; TF-115-BCP9; GND; R? 47 kOhm; R? 47 kOhm 1 2; 47 kOhm 1 2; GND 1 2; MicroSD_SW; MicroSD_D0; MicroSD_D2; MicroSD_D1; MicroSD_D3 MicroSD_CMD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

Size; Number; Revision; Date:; Sheet of; File:; C:\Work\Altium\EDR\QSPI&SPI.SchDoc Drawn By:; STM32H7 Board[1A] QSPI; QSPI_BK1_IO3; QSPI_BK1_IO0; QSPI_BK1_IO1; QSPI_BK1_IO2; QSPI_BK1_NCS; QSPI_CLK; QSPI; STM32H7 Board[1A] SPIx; SPIx_MISO SPIx_MOSI SPIx_CLK SPIx_CS; SPIx; CLK 6; VCC; GND; W25Q64JVSSIQ; 33 Ohms; R? 100kOhm; SPI_Flash_MISO; SPI_Flash_MISO SPI_Flash_MOSI; SPI_Flash_MOSI SPI_Flash_CLK; SPI_Flash_CLK SPI_Flash_CS; SPI_Flash_CS

/HOLD OR /RESET(IO3) 7

Title
QSPI&SPI FLASH

Title; Size; Number; Revision; Date:; Sheet of; File:; C:\Work\Altium\EDR\PI_CON.SchDoc; Drawn By:; STM32H7 Board[1A] USB1_DN; STM32H7 Board[1B] USB1_DP; USB_DN; USB_DP; CC1 A5 DP1 A6 DN1 A7 SBU1 A8; VBUS; SBU2; GND; SHELL_GND; USB C 16P; VBUS VBUS; USB_CC1; USB_CC2; VREGIN 7; VBUS 8 D+ 3 D- 4; CTS 18 RTS 19 DSR 22 DCD 24 DTR 23; RXD 20 TXD 21; VDD; VIO; RST; RI/CLK; SUSPEND; SUSPENDB; GPIO.0/TXT; GPIO.1/RXT; GPIO.2/RS485; GPIO.3/WAKEUP; CP2102N-A02-GQFN24R; VBUS2; VBUS2 VBUS2; USB2_CC1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

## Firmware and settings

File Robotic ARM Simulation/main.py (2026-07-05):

"""
╔══════════════════════════════════════════════════════════════╗
║         NEURAL NEXUS — Industrial 6-DOF Robotic Arm HMI      ║
║         Phase 1 Prototype — Apple Light Theme + Slider UX     ║
║         Target: Raspberry Pi 5 + 10.1″ 1280×800 Touch Screen  ║
╚══════════════════════════════════════════════════════════════╝
"""

import sys
import json
import time
import traceback
from typing import Optional

import numpy as np

from PyQt6.QtWidgets import (
    QLineEdit,
    QApplication, QMainWindow, QWidget,
    QVBoxLayout, QHBoxLayout,
    QPushButton, QLabel, QSlider, QCheckBox,
    QComboBox, QFrame, QGraphicsDropShadowEffect,
    QScrollArea,
)
from PyQt6.QtCore import Qt, QThread, pyqtSignal, QObject, QTimer
from PyQt6.QtGui import QFont, QColor, QPalette

# ── Optional dependencies ─────────────────────────────────────────────────────
try:
    import pyqtgraph.opengl as gl
    OPENGL_AVAILABLE = True
except ImportError:
    OPENGL_AVAILABLE = False
    print("[WARN] pyqtgraph / PyOpenGL not installed — 3D viewport disabled.")

try:
    import serial
    import serial.tools.list_ports
    SERIAL_AVAILABLE = True
except ImportError:
    SERIAL_AVAILABLE = False
    print("[WARN] pyserial not installed — hardware mode unavailable.")




# ══════════════════════════════════════════════════════════════════════════════
#  DESIGN TOKENS  — Apple Light (apple.com / SF / HIG)
# ══════════════════════════════════════════════════════════════════════════════
class T:
    # Background layers
    WINDOW    = "#F5F5F7"   # outermost chrome
    CARD      = "#FFFFFF"   # floating panel surface
    INPUT_BG  = "#F5F5F7"   # subtle recessed fill
    HOVER     = "#E8E8ED"
    PRESS     = "#D2D2D7"

    # Accent
    BLUE      = "#0071E3"
    BLUE_H    = "#0077ED"   # hover
    BLUE_P    = "#006EDB"   # pressed
    GREEN     = "#34C759"
    RED       = "#FF3B30"
    ORANGE    = "#FF9500"

    # Text — HIG label hierarchy
    INK1      = "#1D1D1F"   # primary  — 100 %
    INK2      = "#86868B"   # secondary — ~52 %
    INK3      = "#C7C7CC"   # tertiary  — ~35 %

    # Borders
    BORDER    = "#E5E5EA"   # element boundary
    SEP       = "#D2D2D7"   # section separator

    # Radius
    R_SM      = "10px"
    R_MD      = "14px"
    R_LG      = "16px"
    R_XL      = "20px"
    R_PILL    = "999px"

    # ── Apple web font stack ──────────────────────────────────────────────────
    # Priority: SF Pro → system sans → Segoe UI (Windows) → Roboto → Helvetica
    FONT      = ("San Francisco", "-apple-system", "BlinkMacSystemFont", "Segoe UI", "sans-serif")

    @staticmethod
    def ipad_shadow():
        from PyQt6.QtWidgets import QGraphicsDropShadowEffect
        from PyQt6.QtGui import QColor
        fx = QGraphicsDropShadowEffect()
        fx.setBlurRadius(25)
        fx.setOffset(0, 2)
        c = QColor("#000000")
        c.setAlpha(int(0.08 * 255))
        fx.setColor(c)
        return fx

    @staticmethod
    def shadow(blur: int = 28, y: int = 6, alpha: int = 16) -> QGraphicsDropShadowEffect:
        """Ambient card shadow — super-soft, barely-there."""
        fx = QGraphicsDropShadowEffect()
        fx.setBlurRadius(blur)
        c = QColor("#000000")
        c.setAlpha(alpha)
        fx.setColor(c)
        fx.setOffset(0, y)
        return fx

    @staticmethod
    def glow(color: str = "#0071E3", blur: int = 18, alpha: int = 55) -> QGraphicsDropShadowEffect:
        fx = QGraphicsDropShadowEffect()
        fx.setBlurRadius(blur)
        c = QColor(color)
        c.setAlpha(alpha)
        fx.setColor(c)
        fx.setOffset(0, 2)
        return fx

    @staticmethod
    def best_font(size: int = 11, weight: QFont.Weight = QFont.Weight.Normal) -> QFont:
        """Return a QFont from the Apple web font priority stack."""
        for family in T.FONT:
            f = QFont(family, size, weight)
            if f.exactMatch():
                return f
        # Fallback: just ask Qt for sans-serif
        f = QFont()
        f.setStyleHint(QFont.StyleHint.SansSerif)
        f.setPointSize(size)
        f.setWeight(weight)
        return f


# ── Global QSS applied to QApplication ───────────────────────────────────────
_GLOBAL_QSS = f"""
* {{
    font-family: "San Francisco", "-apple-system", "BlinkMacSystemFont", "Segoe UI", sans-serif;
    outline: 0;
}}
QMainWindow {{ background: {T.WINDOW}; }}

/* ── Slider: groove — iOS Control Center style ── */
QSlider::groove:horizontal {{
    height: 6px;
    background: #E5E5EA;
    border-radius: 3px;
    margin: 0 6px;
}}
QSlider::sub-page:horizontal {{
    background: {T.BLUE};
    border-radius: 3px;
    height: 6px;
}}
QSlider::add-page:horizontal {{
    background: #E5E5EA;
    border-radius: 3px;
    height: 6px;
}}
QSlider::handle:horizontal {{
    width: 26px;
    height: 26px;
    margin: -10px -2px;
    border-radius: 13px;
    background: {T.CARD};
    border: 1px solid #D2D2D7;
}}
QSlider::handle:horizontal:hover {{
    border: 1.5px solid #C7C7CC;
}}
QSlider::handle:horizontal:pressed {{
    background: #F0F0F2;
    border: 1.5px solid #C7C7CC;
}}

QToolTip {{
    background: {T.CARD};
    color: {T.INK1};
    border: 1px solid {T.BORDER};
    border-radius: {T.R_SM};
    padding: 4px 10px;
    font-size: 9pt;
}}
"""

SLIDER_RANGE = (-180, 180)   # degrees, default joint angle limits

# ══════════════════════════════════════════════════════════════════════════════
#  JOINT SPACE SAFETY LIMITS — Hardware-enforced per-joint boundaries
#  Format: (min_angle, max_angle) in degrees
# ══════════════════════════════════════════════════════════════════════════════
JOINT_LIMITS = [
    (-180, 180),    # θ1  Base Yaw       — full rotation
    (-10,  150),    # θ2  Shoulder Pitch  — prevent floor collision
    (-120, 120),    # θ3  Elbow Pitch     — realistic elbow range
    (-180, 180),    # θ4  Wrist Roll      — full rotation
    (-90,   90),    # θ5  Wrist Pitch     — standard wrist flex
    (-180, 180),    # θ6  Tool Roll       — full rotation
]

# Cartesian workspace safety floor (mm)
Z_FLOOR_LIMIT = 0.0


# ══════════════════════════════════════════════════════════════════════════════
#  PROCEDURAL GEOMETRY GENERATORS
# ══════════════════════════════════════════════════════════════════════════════

# Polished aluminum finish
_COLOR_ALUMINUM = (0.75, 0.76, 0.78, 1.0)
# Apple Blue accent for end-effector
_COLOR_APPLE_BLUE = (0.00, 0.44, 0.89, 1.0)
# Darker accent for joint spheres
_COLOR_JOINT = (0.60, 0.61, 0.63, 1.0)
_COLOR_JOINT_TIP = (0.00, 0.36, 0.73, 1.0)


def create_link_mesh(radius: float, length: float, color: tuple) -> 'gl.GLMeshItem':
    """
    Generate a polished cylinder primitive along the Z-axis.
    Base at z=0, tip at z=length.
    """
    md = gl.MeshData.cylinder(rows=12, cols=24, radius=[radius, radius], length=length)
    item = gl.GLMeshItem(
        meshdata=md,
        color=color,
        shader='shaded',
        smooth=True,
        drawFaces=True,
        drawEdges=False,
    )
    item.setGLOptions('opaque')
    return item


def create_joint_sphere(radius: float, color: tuple) -> 'gl.GLMeshItem':
    """
    Generate a sphere at a joint origin for visual articulation clarity.
    """
    md = gl.MeshData.sphere(rows=12, cols=24, radius=radius)
    item = gl.GLMeshItem(
        meshdata=md,
        color=color,
        shader='shaded',
        smooth=True,
        drawFaces=True,
        drawEdges=False,
    )
    item.setGLOptions('opaque')
    return item


# ══════════════════════════════════════════════════════════════════════════════
#  PROCEDURAL KINEMATICS CONFIG — Standard 6-DOF Sequential Chain
#  Cylinders generate along Z. Translation to next joint = Z + length.
#  Joint order: Yaw → Pitch → Pitch → Roll → Pitch → Roll
# ══════════════════════════════════════════════════════════════════════════════
ROBOT_KINEMATICS_CONFIG = [
    {
        "name": "base",
        "length": 100.0,
        "radius": 45.0,
        "rotation_axis": [0, 0, 1],   # Yaw
        "color": _COLOR_ALUMINUM,
    },
    {
        "name": "shoulder",
        "length": 350.0,
        "radius": 35.0,
        "rotation_axis": [0, 1, 0],   # Pitch
        "color": _COLOR_ALUMINUM,
    },
    {
        "name": "elbow",
        "length": 300.0,
        "radius": 25.0,
        "rotation_axis": [0, 1, 0],   # Pitch
        "color": _COLOR_ALUMINUM,
    },
    {
        "name": "wrist_roll",
        "length": 60.0,
        "radius": 20.0,
        "rotation_axis": [0, 0, 1],   # Roll
        "color": _COLOR_ALUMINUM,
    },
    {
        "name": "wrist_pitch",
        "length": 60.0,
        "radius": 18.0,
        "rotation_axis": [0, 1, 0],   # Pitch
        "color": _COLOR_ALUMINUM,
    },
    {
        "name": "end_effector",
        "length": 50.0,
        "radius": 15.0,
        "rotation_axis": [0, 0, 1],   # Roll
        "color": _COLOR_APPLE_BLUE,
    },
]


def validate_posture_safety(test_angles: list) -> bool:
    """
    Pure-math FK preview — runs the kinematic chain offline to check
    if a proposed set of joint angles causes floor collision (TCP Z < 0).

    Returns True if safe (TCP Z >= 0), False if collision.
    """
    import pyqtgraph as pg

    parent_transform = pg.Transform3D()

    for i, conf in enumerate(ROBOT_KINEMATICS_CONFIG):
        global_transform = pg.Transform3D(parent_transform)

        axis = conf['rotation_axis']
        angle = test_angles[i] if i < len(test_angles) else 0.0
        global_transform.rotate(angle, axis[0], axis[1], axis[2])

        parent_transform = pg.Transform3D(global_transform)
        parent_transform.translate(0, 0, conf['length'])

    tcp_vec = parent_transform.map(pg.Vector(0, 0, 0))
    return tcp_vec.z() >= Z_FLOOR_LIMIT




# ══════════════════════════════════════════════════════════════════════════════
#  SERIAL WORKER  (QThread — logic unchanged)
# ══════════════════════════════════════════════════════════════════════════════
class SerialWorkerSignals(QObject):
    success = pyqtSignal(str)
    error   = pyqtSignal(str)
    log     = pyqtSignal(str)


class SerialWorker(QThread):
    def __init__(self, payload: str, hardware_mode: bool,
                 port: str = "COM3", baud: int = 115200):
        super().__init__()
        self.payload       = payload
        self.hardware_mode = hardware_mode
        self.port          = port
        self.baud          = baud
        self.signals       = SerialWorkerSignals()

    def run(self) -> None:
        try:
            if self.hardware_mode and SERIAL_AVAILABLE:
                self._send_hardware()
            else:
                self._send_mock()
        except Exception as exc:
            self.signals.error.emit(f"Worker exception: {exc}\n{traceback.format_exc()}")

    def _send_hardware(self) -> None:
        self.signals.log.emit(f"[HW] Opening {self.port} @ {self.baud} baud …")
        try:
            with serial.Serial(self.port, self.baud, timeout=2) as ser:
                ser.write((self.payload + "\n").encode("utf-8"))
                self.signals.log.emit(f"[HW]  TX → {self.payload}")
                ack = ser.readline().decode("utf-8", errors="replace").strip()
                self.signals.log.emit(f"[HW]  RX ← {ack or '(no ACK)'}")
            self.signals.success.emit(self.payload)
        except serial.SerialException as exc:
            self.signals.error.emit(f"Serial error: {exc}")

    def _send_mock(self) -> None:
        self.signals.log.emit("[PC]  Simulating UART TX (50 ms delay) …")
        time.sleep(0.05)
        self.signals.log.emit(f"[PC]  TX payload → {self.payload}")
        print(f"[NEURAL NEXUS MOCK TX] {self.payload}")
        self.signals.success.emit(self.payload)


# ══════════════════════════════════════════════════════════════════════════════
#  PRIMITIVES
# ══════════════════════════════════════════════════════════════════════════════

class Card(QFrame):
    """White floating card with ambient drop shadow."""
    def __init__(self, radius: str = T.R_LG, parent=None):
        super().__init__(parent)
        self.setAttribute(Qt.WidgetAttribute.WA_StyledBackground, True)
        self.setStyleSheet(f"""
            Card {{
                background: {T.CARD};
                border: 1px solid #EBEBF0;
                border-radius: 18px;
            }}
        """)
        self.setGraphicsEffect(T.shadow(blur=32, y=6, alpha=13))


class SectionLabel(QLabel):
    def __init__(self, text: str, parent=None):
        super().__init__(text.upper(), parent)
        self.setFont(T.best_font(10, QFont.Weight.DemiBold))
        self.setStyleSheet(f"""
            QLabel {{
                color: {T.INK2};
                letter-spacing: 0.8px;
                background: transparent;
            }}
        """)
        self.setContentsMargins(2, 4, 0, 8)


class Divider(QFrame):
    def __init__(self, parent=None):
        super().__init__(parent)
        self.setFixedHeight(1)
        self.setStyleSheet("background: #EBEBF0; border: none;")


# ══════════════════════════════════════════════════════════════════════════════
#  AXIS CONTROL ROW  — value label + slider, all inside a white card row
# ══════════════════════════════════════════════════════════════════════════════
class AxisRow(QWidget):
    """
    One self-contained row: axis badge | large value label | unit | slider.
    The slider drives the value display; the display value is the
    single source of truth for what gets sent.
    """

    value_changed = pyqtSignal(float)   # emits the new float whenever slider moves

    def __init__(self, axis: str, accent_color: str, label: str = "",
                 limits: tuple = None, parent=None):
        super().__init__(parent)
        self.axis   = axis
        self.accent = accent_color
        self._label = label or f"{axis}-Axis"
        self._limits = limits or SLIDER_RANGE
        self.setAttribute(Qt.WidgetAttribute.WA_StyledBackground, True)
        self.setStyleSheet("background: transparent;")
        self._build()

    def _build(self):
        root = QVBoxLayout(self)
        root.setContentsMargins(16, 8, 16, 8)
        root.setSpacing(6)
        self.setMinimumHeight(65)

        # ── Top row: badge + value + unit ──────────────────────────────────
        top = QHBoxLayout()
        top.setSpacing(14)
        top.setContentsMargins(0, 0, 0, 0)

        # Axis circle badge
        self._badge = QLabel(self.axis)
        self._badge.setFixedSize(36, 36)
        self._badge.setAlignment(Qt.AlignmentFlag.AlignCenter)
        self._badge.setStyleSheet(f"""
            QLabel {{
                background-color: #F5F5F7;
                border: 1px solid #E5E5EA;
                border-radius: 18px;
                font-size: 14px;
                font-weight: 600;
                color: #86868B;
            }}
        """)
        top.addWidget(self._badge)

        # Large numeric value
        self._val = QLabel("0.0")
        self._val.setMinimumWidth(110)
        self._val.setAlignment(Qt.AlignmentFlag.AlignLeft | Qt.AlignmentFlag.AlignVCenter)
        self._val.setStyleSheet(f"""
            QLabel {{
                font-size: 24px;
                font-weight: 700;
                color: #1D1D1F;
                background: transparent;
            }}
        """)
        top.addWidget(self._val, stretch=1)

        # Sub-label
        meta = QVBoxLayout()
        meta.setSpacing(0)
        axis_lbl = QLabel(self._label)
        axis_lbl.setFont(T.best_font(9, QFont.Weight.Medium))
        axis_lbl.setStyleSheet(f"color: {T.INK2}; background: transparent;")
        unit_lbl = QLabel("deg")
        unit_lbl.setFont(T.best_font(9))
        unit_lbl.setStyleSheet(f"color: {T.INK3}; background: transparent;")
        meta.addWidget(axis_lbl)
        meta.addWidget(unit_lbl)
        top.addLayout(meta)

        root.addLayout(top)

        # ── Slider ──────────────────────────────────────────────────────────
        slider_row = QHBoxLayout()
        slider_row.setSpacing(8)
        slider_row.setContentsMargins(0, 0, 0, 0)

        lo_lbl = QLabel(f"{self._limits[0]}°")
        lo_lbl.setFont(T.best_font(8))
        lo_lbl.setStyleSheet(f"color: {T.INK3}; background: transparent;")
        slider_row.addWidget(lo_lbl)

        self.slider = QSlider(Qt.Orientation.Horizontal)
        self.slider.setRange(self._limits[0], self._limits[1])
        # Start at 0 if within range, otherwise at midpoint
        init_val = 0 if self._limits[0] <= 0 <= self._limits[1] else (self._limits[0] + self._limits[1]) // 2
        self.slider.setValue(init_val)
        self.slider.setFixedHeight(30)
        self.slider.valueChanged.connect(self._on_slide)
        slider_row.addWidget(self.slider, stretch=1)

        hi_lbl = QLabel(f"{self._limits[1]}°")
        hi_lbl.setFont(T.best_font(8))
        hi_lbl.setStyleSheet(f"color: {T.INK3}; background: transparent;")
        slider_row.addWidget(hi_lbl)

        root.addLayout(slider_row)

    def _on_slide(self, raw: int):
        val = float(raw)
        self._val.setText(f"{val:.1f}°")
        self.value_changed.emit(val)

    # ── public API ────────────────────────────────────────────────────────────
    def get_value(self) -> float:
        return float(self.slider.value())

    def set_value(self, v: float):
        self.slider.setValue(int(round(v)))


# ══════════════════════════════════════════════════════════════════════════════
#  SEND BUTTON
# ══════════════════════════════════════════════════════════════════════════════
class SendButton(QPushButton):
    _CFG = {
        "idle":  (T.BLUE,  T.BLUE_H,  T.BLUE_P,  "#FFFFFF", "Send Coordinates"),
        "ok":    (T.GREEN, "#2EBD50", "#28A845", "#FFFFFF", "✓  Coordinates Sent"),
        "error": (T.RED,   "#FF5247", "#E5352C", "#FFFFFF", "✕  Transmission Error"),
    }

    def __init__(self, parent=None):
        super().__init__(parent)
        self.setFixedHeight(44)
        self.setCursor(Qt.CursorShape.PointingHandCursor)
        self.setFont(T.best_font(15, QFont.Weight.Bold))
        self._apply("idle")

    def _apply(self, state: str):
        bg, hv, pr, fg, txt = self._CFG[state]
        self.setText(txt)
        self.setStyleSheet(f"""
            QPushButton {{
                background: {bg};
                color: {fg};
                border: none;
                border-radius: 10px;
                font-size: 15px;
                font-weight: 600;
                letter-spacing: 0.3px;
                padding: 0 28px;
            }}
            QPushButton:hover  {{ background: {hv}; }}
            QPushButton:pressed {{ background: {pr}; }}
            QPushButton:disabled {{
                background: #E5E5EA;
                color: {T.INK3};
            }}
        """)
        glow_color = {"idle": T.BLUE, "ok": T.GREEN, "error": T.RED}[state]
        self.setGraphicsEffect(T.glow(glow_color, blur=20, alpha=50))

    def set_state(self, s: str):
        self._apply(s)


# ══════════════════════════════════════════════════════════════════════════════
#  iOS-STYLE TOGGLE SWITCH
# ══════════════════════════════════════════════════════════════════════════════
class Toggle(QCheckBox):
    def __init__(self, parent=None):
        super().__init__(parent)
        self.setFixedSize(48, 28)
        self.setCursor(Qt.CursorShape.PointingHandCursor)
        self.setStyleSheet(f"""
            QCheckBox {{ spacing: 0; background: transparent; }}
            QCheckBox::indicator {{
                width: 48px; height: 28px;
                border-radius: 14px;
                background: {T.BORDER};
                border: none;
            }}
            QCheckBox::indicator:checked   {{ background: {T.GREEN}; }}
            QCheckBox::indicator:unchecked:hover {{ border: 1.5px solid {T.BLUE}; }}
        """)


# ══════════════════════════════════════════════════════════════════════════════
#  STATUS BAR
# ══════════════════════════════════════════════════════════════════════════════
class StatusBar(QFrame):
    def __init__(self, parent=None):
        super().__init__(parent)
        self.setFixedHeight(36)
        self.setStyleSheet(f"""
            QFrame {{
                background: {T.CARD};
                border-top: 1px solid #EBEBF0;
            }}
        """)
        hl = QHBoxLayout(self)
        hl.setContentsMargins(24, 0, 24, 0)
        hl.setSpacing(8)

        self._dot = QLabel("●")
        self._dot.setFont(T.best_font(8))
        self._dot.setFixedWidth(14)
        hl.addWidget(self._dot)

        self._msg = QLabel("System ready  —  PC Test Mode")
        self._msg.setFont(T.best_font(9))
        hl.addWidget(self._msg, stretch=1)

        self._clock = QLabel("--:--:--")
        self._clock.setFont(T.best_font(9))
        self._clock.setStyleSheet(f"color: {T.INK3}; background: transparent;")
        hl.addWidget(self._clock)

        timer = QTimer(self)
        timer.timeout.connect(self._tick)
        timer.start(1000)
        self._tick()
        self.log("System ready  —  PC Test Mode", "idle")

    def _tick(self):
        from datetime import datetime
        self._clock.setText(datetime.now().strftime("%H:%M:%S"))

    def log(self, msg: str, level: str = "idle"):
        dot = {"idle": T.INK3, "info": T.BLUE, "ok": T.GREEN,
               "warn": T.ORANGE, "error": T.RED}
        txt = {"idle": T.INK2, "info": T.INK1, "ok": T.GREEN,
               "warn": T.ORANGE, "error": T.RED}
        self._dot.setStyleSheet(f"color: {dot.get(level, T.INK2)}; background: transparent;")
        self._msg.setStyleSheet(f"color: {txt.get(level, T.INK2)}; background: transparent;")
        self._msg.setText(msg)
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

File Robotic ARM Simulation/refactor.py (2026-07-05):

import sys

with open('main.py', 'r', encoding='utf-8') as f:
    text = f.read()

# 1. Update font stack
text = text.replace('("San Francisco", "Segoe UI", "Roboto", "Helvetica Neue", "Arial")', '("San Francisco", "-apple-system", "BlinkMacSystemFont", "Segoe UI", "sans-serif")')
text = text.replace('font-family: "San Francisco", "Segoe UI", "Roboto", "Helvetica Neue", Arial, sans-serif;', 'font-family: "San Francisco", "-apple-system", "BlinkMacSystemFont", "Segoe UI", sans-serif;')

# 2. Add ipad_shadow
shadow_func = '''    @staticmethod
    def ipad_shadow():
        from PyQt6.QtWidgets import QGraphicsDropShadowEffect
        from PyQt6.QtGui import QColor
        fx = QGraphicsDropShadowEffect()
        fx.setBlurRadius(25)
        fx.setOffset(0, 2)
        c = QColor("#000000")
        c.setAlpha(int(0.08 * 255))
        fx.setColor(c)
        return fx

    @staticmethod
    def shadow'''
text = text.replace('    @staticmethod\n    def shadow', shadow_func)

# 3. ViewportPanel rewrite
v_old = '''class ViewportPanel(QFrame):
    def __init__(self, parent=None):
        super().__init__(parent)
        self.setAttribute(Qt.WidgetAttribute.WA_StyledBackground, True)
        self.setStyleSheet(f"""
            ViewportPanel {{
                background: {T.WINDOW};
                border-left: 1px solid #EBEBF0;
            }}
        """)

        outer = QVBoxLayout(self)
        outer.setContentsMargins(16, 16, 16, 16)
        outer.setSpacing(0)

        # White card wrapping the OpenGL widget
        self._card = QFrame()
        self._card.setAttribute(Qt.WidgetAttribute.WA_StyledBackground, True)
        self._card.setStyleSheet(f"""
            QFrame {{
                background: {T.CARD};
                border: 1px solid #EBEBF0;
                border-radius: 18px;
            }}
        """)
        self._card.setGraphicsEffect(T.shadow(blur=36, y=8, alpha=14))

        card_vl = QVBoxLayout(self._card)
        card_vl.setContentsMargins(0, 0, 0, 0)
        card_vl.setSpacing(0)

        card_vl.addWidget(self._make_header())

        if OPENGL_AVAILABLE:
            self._build_gl(card_vl)
        else:
            self._build_fallback(card_vl)

        card_vl.addWidget(self._make_footer())
        outer.addWidget(self._card)'''

v_new = '''class ViewportPanel(QFrame):
    def __init__(self, parent=None):
        super().__init__(parent)
        self.setAttribute(Qt.WidgetAttribute.WA_StyledBackground, True)
        self.setStyleSheet(f"""
            ViewportPanel {{
                background: {T.CARD};
                border-radius: 20px;
            }}
        """)

        card_vl = QVBoxLayout(self)
        card_vl.setContentsMargins(0, 0, 0, 0)
        card_vl.setSpacing(0)

        card_vl.addWidget(self._make_header())

        if OPENGL_AVAILABLE:
            self._build_gl(card_vl)
        else:
            self._build_fallback(card_vl)

        card_vl.addWidget(self._make_footer())'''
text = text.replace(v_old, v_new)

# Viewport make_header & make_footer style fixes
vh_old = '''            QFrame {
                background: {T.CARD};
                border-bottom: 1px solid #EBEBF0;
                border-top-left-radius: 18px;
                border-top-right-radius: 18px;
            }'''
text = text.replace(vh_old, '''            QFrame {\n                background: transparent;\n            }''')

vf_old = '''            QFrame {
                background: {T.CARD};
                border-top: 1px solid #EBEBF0;
                border-bottom-left-radius: 18px;
                border-bottom-right-radius: 18px;
            }'''
text = text.replace(vf_old, '''            QFrame {\n                background: transparent;\n            }''')

# 4. _apply_fk interpolation
fk_old = '''        self._current_angles[:] = self._target_angles[:]
        
        # a) Start with the world root transform'''
fk_new = '''        for i in range(len(self._target_angles)):
            diff = self._target_angles[i] - self._current_angles[i]
            self._current_angles[i] += diff * 0.15
            
        # a) Start with the world root transform'''
text = text.replace(fk_old, fk_new)

with open('main.py', 'w', encoding='utf-8') as f:
    f.write(text)
print('Phase 1 done')
